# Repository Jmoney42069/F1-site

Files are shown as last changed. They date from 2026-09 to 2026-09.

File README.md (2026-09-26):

# dweilrobo

DIY autonomous floor-mopping robot: ESP32 for real-time control, home server for mapping and planning.

- `docs/01-engineering-study.md` — engineering study (architecture, sensors, power, layout, costs, open questions)
- `cad/layout.py` — parametric layout and weight/traction checks (`python3 cad/layout.py`, exits non-zero on failure)
- `cad/layout_top.svg` — generated top view

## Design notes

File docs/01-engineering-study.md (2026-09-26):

# dweilrobo — Engineering Study v0.1

Status: **pre-CAD study**. Nothing here is a purchase decision yet.
Companion files: `cad/layout.py` (parametric layout + load/traction checks), `cad/layout_top.svg` (its output).

Prices are **estimates** of typical 2026 AliExpress prices, not verified listings. The linked, verified BOM is the last step, done after the measurements in §11 are locked. That order is the CAD-first rule you set.

---

## 0. Summary

| Question | Answer |
|---|---|
| Is the €50–70 target realistic? | **Not with reliable mapping.** With a lidar, a robust MVP costs **€100–120** (recommended), or **€80–90** if you reuse cells and consumables. **€65–70** is possible only with no lidar and an old phone as a fixed overhead camera. See §13. |
| Minimum sensor set for real mapping + carpet avoidance | Wheel encoders + gyro (IMU) + **used Xiaomi LDS02RR lidar (~€16)** + 2 bumper switches + 2 downward ToF + the mop-motor encoders. Carpets are **no-go zones drawn on the map**. The onboard sensors are only a safety interlock. |
| Mop moisture sensing | **Don't make it the control loop.** Meter the water per pad by volume (mL/m²) with two peristaltic pumps. Commercial robots do the same. A direct sensor is a phase-3 experiment. See §4. |
| Battery | 3S1P 18650 (11.1 V, ~3 Ah, ~33 Wh), 3S BMS, 5 A fuse. Gives ~1.5 h against a ~17 W average draw. **Buy the cells from an EU shop, not AliExpress.** |
| Motors | 4× the same **JGA25-370 12 V ~130 rpm with Hall encoder**: 2 drive, 2 mop. One SKU gives you spares and stall detection everywhere. |
| Biggest mechanical risk | **The spring force on the mops takes load off the drive wheels.** The layout must keep enough weight on the wheels as the tank drains. `cad/layout.py` checks this, and the first layout **failed** it (§6.3). |

---

## 1. Where your spec is technically weak (read this first)

1. **"Measure each mop's moisture and regulate to 65%" is not practical with cheap parts.** The pad spins, gets dirty, and holds detergent. Its conductivity depends on water hardness and soap far more than on wetness. Resistive probes corrode (electrolysis). A capacitive sensor on a rotating, bouncing pad sees a varying air gap. No commercial mopping robot measures pad moisture. They all dose by area and time. → Control water **per square metre per pad**, and treat "moisture %" as an estimate the model calculates (§4).
2. **Odometry alone will not tell you "where have I cleaned".** A wet floor plus two rotating pads pulling sideways makes the wheels slip. You need an absolute reference. Lidar is the cheapest reliable one; a fixed overhead camera is the cheapest overall (§7).
3. **A camera on the robot is not the cheapest way to localize.** Visual SLAM from an ESP32-CAM over Wi-Fi has low fps, variable latency, motion blur and a camera 10 cm above a featureless floor. That is a research project. Use a camera for recognition later, not for pose.
4. **Your mops cannot lift, so the robot can never drive over a carpet.** Commercial robots lift their pads or detach them at the dock. We don't. So carpets are hard no-go zones, **inflated by the robot radius plus a margin**, because the pads sit behind the axle and swing when the robot turns.
5. **Automatic carpet detection with a €0.50 IR reflectance sensor (TCRT5000) is unreliable.** It measures colour and brightness, not material: a dark floor looks like a dark rug. The reliable signals are map zones, a height step at the rug edge, and extra drag on the pads.
6. **AliExpress 18650 cells** are the one AliExpress category to avoid ("9900 mAh" fakes, unknown chemistry). Saving €5 here risks a fire.
7. **4S is the wrong choice** here. The cheap, good H-bridge (TB6612FNG) is rated to 13.5 V, and 12 V motors are the common variant. 3S (9.0–12.6 V) matches both.
8. **The €50–70 target and "reliable map + coverage + carpet avoidance" pull against each other.** By your own rule (buy the €6 part if it makes the robot robust), the lidar earns its €16.
9. **Which ESP32 do you have?** The classic ESP32 (WROOM) and the S3 have hardware pulse counters (PCNT) for 4 encoders. **The ESP32-C3 has no PCNT and too few pins** — unsuitable as the main controller. The pin budget (§8.3) fits a classic DevKit with only 1 pin to spare.

---

## 2. Subsystem breakdown

```
MECHANICAL                 ELECTRICAL                     SOFTWARE
- base plate / frame       - 3S battery, BMS, fuse,       ESP32 firmware (real time)
- 2 drive pods               switch, charge jack            - wheel PID, odometry, IMU
  (motor+wheel)            - 5 V buck (ESP32, lidar)        - mop + pump control
- front caster             - 3x TB6612FNG                   - safety reflexes, watchdog
- 2 floating mop modules     (drive / mops / pumps)         - lidar driver, telemetry
- tank + cradle            - encoders, IMU, INA219        Server (ROS 2 in Docker)
- 2 pump brackets          - 2 ToF, 2 bumper switches       - bridge (UDP <-> topics)
- sealed battery box       - LDS02RR lidar                  - slam_toolbox (map/pose)
- electronics tray + lid   - wiring, connectors             - Nav2 + keep-out mask (carpet)
- front bumper                                              - coverage planner + cleaned layer
- lidar deck                                                - mop manager (dosing)
                                                            - dashboard (Foxglove / web)
```

---

## 3. Critical unknowns, ranked

| # | Unknown | Why it matters | How to settle it (cheap) |
|---|---|---|---|
| U1 | Pad friction coefficient and torque on **your** floor | Sizes the mop motors, drag, spring force | Bench test: a disc with a cloth, a known weight, a luggage scale on a lever arm |
| U2 | Wheel traction on a wet floor | Everything depends on the wheels not slipping | Pull test with the scale on a wet floor |
| U3 | Floor type (tile vs laminate/parquet) | Laminate/parquet tolerates very little water → dose limits | Tell me |
| U4 | Clearance under sofa / TV cabinet | Sets the maximum height (the lidar turret makes the robot ~150 mm tall) | Measure |
| U5 | Rug types and edge heights; do rugs move? | Moving rugs make map zones unreliable → onboard detection gets more important | Measure / tell me |
| U6 | Real dimensions of the chosen motor, pump, lidar and holder variants | The CAD depends on them; listings vary by ratio and seller | Measure after ordering **one** of each (§11) |
| U7 | Your ESP32 board | PCNT and pin count | Tell me the board name |
| U8 | 3D printer and bed size | Frame split into segments vs plywood | Tell me |

---

## 4. Moisture and water system

### 4.1 Sensing options, judged

| Method | Works? | Why |
|---|---|---|
| Resistive (2 electrodes in the pad) | Poor | Electrolysis corrodes the electrodes; reading depends on hardness and soap; contact on a rotating pad wears it |
| Capacitive (soil-sensor type) | Poor on a moving pad | Varying air gap, bounce, dirt. Works on a *stationary* reference sponge only |
| Conductivity with AC excitation | Relative trend only | Needs per-session calibration (dry vs soaked); still drifts with soap |
| Mop-motor load (encoder rpm at fixed PWM) | Weak for moisture | Floor, dirt and carpet dominate the signal. **Excellent for carpet/snag detection though** |
| **Metered water delivery (peristaltic)** | **Yes** | Volume per pump revolution is repeatable ±5–10%. Known mL/m² per pad is the quantity that matters |
| Tank level (capacitive, through the wall) | Yes | ESP32 touch pin + 2 copper-tape electrodes on the outside of the tank. Free. Detects empty tank and cross-checks the pumped volume |

### 4.2 Control approach (MVP)

```
target_dose  [mL/m²]   (per floor type, e.g. start at 3–5 mL/m², calibrate)
area_rate    [m²/s]  = speed × pad_width (from odometry, per pad)
pump_rate    [mL/s]  = target_dose × area_rate  (+ a pre-wet burst at start)
pump_pwm            ← calibration table mL/s → PWM (measured with a cup)
wetness_est  (per pad) integrates dosed water minus a transfer model, shown as your "LEFT 60% / RIGHT 43%"
```
Pumps stop immediately when the robot stops, a carpet or cliff is suspected, the tank is empty, the robot enters a no-go zone, or the server link is lost.

### 4.3 Pump choice: **two peristaltic pumps**, no splitter

- **One pump + Y-splitter:** the flow splits by tube resistance and air bubbles, so you can't control it per side. Cheap but gives an uneven result.
- **Diaphragm pump:** far too much flow (~1 L/min) for ~20 mL/min, and it **siphons/leaks when off**, so it needs a check valve and solenoid.
- **Peristaltic pump:** self-priming, **seals when stopped** (no leaks, no valves), flow ∝ speed, tolerates running dry. A second pump costs ~€5. **Worth it.** Pick the **low-flow variant (1×3 mm tube, ~5–40 mL/min at 12 V)**.

Flow needed: 5 mL/m² × 0.2 m/s × 0.27 m ≈ 0.27 mL/s ≈ **16 mL/min total**. A 25 m² room at 5 mL/m² uses ~125 mL, so a 300 mL tank is enough.

### 4.4 Leak-proof tank

- **No holes in the bottom of the tank.** The suction tube enters through the lid and reaches the bottom (weighted tip). Refilling = lift the lid and pull the tube out.
- The tank sits **over the axle** (so the balance doesn't change as it drains, §6.3). A drip tray under it drains *away* from the electronics.
- Pump → silicone tube → **stationary drip nozzle** over an annular trough in the rotating pad disc → holes → cloth. There is no rotating seal.

---

## 5. Motors, wheels, mops

### 5.1 Requirements

Mass ≈ **2.2 kg full** (see `cad/layout.py`).

- Drive: cruise 0.2 m/s, max ~0.4 m/s. Force ≈ rolling resistance (~0.6 N) + pad drag (~1.1 N while spinning, ~3.7 N if stalled) + a threshold/ramp margin → design for **~4 N total, ~2 N per wheel**. With a 65 mm wheel that is 0.065 N·m ≈ **0.7 kg·cm per motor** continuous, and more to climb a threshold.
- Speed: 0.4 m/s ÷ (π × 0.065 m) ≈ 118 rpm → **~130 rpm at 12 V**. It still gives ~100 rpm at 9.6 V; the PID handles the difference.
- Mops: friction torque ≈ ⅔·μ·N·R = ⅔ × 0.5 × 3.7 N × 0.065 m ≈ **0.8 kg·cm per pad**, 120–200 rpm.

### 5.2 Choice: JGA25-370, 12 V, ~130 rpm, with Hall encoder (×4)

- Gearbox Ø25 mm, 4 mm D-shaft (~10–12 mm long), 2× M3 on the gearbox face (spacing reported as 17 mm in some drawings — **VERIFY**), 11 PPR Hall encoder → ~1500–2000 counts per wheel revolution after ×4 decoding and the gear ratio. Rated torque at 130 rpm is roughly 1–2 kg·cm, stall much higher: enough margin for both jobs.
- Alternatives rejected:
  - **N20**: too weak for 2.2 kg plus pad drag.
  - **TT yellow motor**: plastic gears, backlash, poor encoders.
  - **BLDC**: needs an extra controller per motor and costs more, for no gain at these speeds.
- Mops use the **same SKU**: identical spares, and the encoder gives mop rpm, which is the carpet/snag/stall signal. Budget option: mops without an encoder (−€5 total), but then you lose that signal.
- Height: a vertical mop motor with encoder stands ~70 mm above the plate. If the height budget (U4) is tight, the lower alternative is the **JGY-370 worm-gear** motor mounted flat (right-angle output).

### 5.3 Wheels and caster

- 65 mm rubber wheels on a 4 mm D/hex coupler, or a printed hub with a TPU tyre. Axle height 32.5 mm → motor underside at ~20 mm → **ground clearance 20 mm**, enough for thresholds up to ~10 mm.
- One ball caster at the front (x = +150 mm). No rear caster: the mops are the rear support.

### 5.4 Mop module (floating)

```
      motor (fixed to plate, shaft down)
          │ 4 mm D-shaft → printed hex adapter
  ════════╪════════  base plate (z≈45–49)
          │  hex slider: hub slides ±8 mm on hex
       [spring]  preload screw → 2–5 N per pad
     ┌────┴────┐  TPU flex ring → a few degrees of tilt
     │ disc Ø130│  annular water trough + holes, hook tape underneath
     └─────────┘  microfiber pad (cut from cloth or bought circles), z 0–12
```
Pads: **Ø130 mm**, counter-rotating so the side forces cancel. The gyro heading loop corrects any leftover yaw. To swap a pad, pull it off the hook tape.

Known limitation: the pads sit ~42 mm inside the outline, so a strip ~4 cm wide along the walls stays unmopped. That is acceptable for v1.

---

## 6. Physical layout

### 6.1 Top view (from `cad/layout.py`)

Round Ø350 mm body, drive axle through the centre (so it can turn in place), mops at the rear, electronics at the front and top, water and battery away from the electronics.

top view

| Item | Position (x fwd, y left) mm |
|---|---|
| Drive wheels | x 0, y ±135 |
| Mop centres | x −85, y ±68, Ø130, 6 mm gap between them, 10 mm clearance to the wheels |
| Front caster | x +150 |
| Tank 80×100×50 (~330 mL usable) | over the axle, x −45…+35 |
| Battery 3S1P in a sealed box | between the mop motors, x −120…−60 |
| Electronics tray (ESP32, 3× TB6612, buck, INA219) | front, x +45…+135, raised, with a lid |
| Lidar | top deck, centred over the axle, highest point |
| Bumper | front 140° arc, 2 micro-switches |
| Cliff/rug-edge ToF ×2 | front-left/right, under the bumper, facing down |

### 6.2 Side stack (z)

| z (mm) | Layer |
|---|---|
| 0–12 | microfiber pad + disc |
| 12–30 | sliding hub, spring, ±8 mm travel |
| 20–45 | drive motors (axle at 32.5) |
| 45–49 | base plate (4 mm plywood or 3 mm PETG) |
| 49–100 | tank, pumps, battery box, electronics tray |
| 49–~120 | mop motors (vertical, with encoder) |
| ~125 | top deck |
| ~125–~165 | LDS02RR turret (**VERIFY height**) |

**Total height is about 160 mm.** This robot won't fit under most sofas. Decide this with measurement U4 before CAD.

### 6.3 Weight distribution — the check that failed first

Three groups carry the chassis: the wheels, the caster, and the mop springs. The spring force on the mops **pushes the chassis up** and puts load on the caster, both of which **take load off the wheels**. First layout (tank at the rear, battery in front, 4 N per pad):

```
[empty tank] traction 1.6 N vs stalled-pad drag 4.0 N   FAIL
```
Fix (current layout, all checks OK):
- The **tank goes over the axle**, so draining it doesn't move the centre of gravity (CG x ≈ −9 mm full and empty).
- The **battery goes behind the axle**.
- Spring preload is **3 N per pad** (adjustable 2–5 N), and the caster moves forward to x = +150.
- Result: wheel load 8.7–12.1 N → traction 3.5–4.8 N vs ~1.1 N drag with the pads spinning (≥3× margin).
- A **stalled pad (3.7 N drag) is at the traction limit**, so the firmware must stop the drive when mop rpm collapses. That also serves as the carpet/snag reflex.

Rule for the CAD: **any change to mass or position → rerun `python3 cad/layout.py`**. It exits non-zero on failure.

### 6.4 Water protection

Water sits rear/low, electronics front/high, with a printed splash wall between them. Keep the battery box sealed, route tubes with drip loops, put the electronics lid on top, and don't route water tubing over the electronics tray.

---

## 7. Navigation, mapping, localization

### 7.1 Comparison

| Option | Cost | Gives | Verdict |
|---|---|---|---|
| Wheel odometry | €0 (encoders) | Short-term motion | Needed, but drifts (slip on a wet floor) |
| IMU gyro (BMI160/MPU6050) | €2 | Heading, much better than odometry for turns | Needed |
| Front ToF array | €2 each | Near obstacles in a narrow cone | Nice-to-have; the bumper covers low obstacles |
| Ultrasonic | €1 | Wide, noisy, poor at angles | No |
| **2D lidar LDS02RR (used, ~€16)** | €16 | 360° scan → occupancy map, localization, obstacles | **Yes, the best value per euro.** Supported on ESP32 by the [kaiaai/LDS](https://github.com/kaiaai/LDS) library |
| New lidar (LD06/LD19/RPLIDAR A1) | €60–100 | Same, new | Only if the used LDS02RR disappoints |
| Fixed overhead camera + ArUco marker on the robot | €0 (old phone) to €20 | Absolute pose, top-down view, easy carpet drawing | **The €65 variant / backup.** Single room only, blocked under furniture, poor at night |
| ESP32-CAM on the robot | €7 | Recognition, future learning | Phase 4. Not for localization |
| Visual odometry / visual SLAM | — | — | Too fragile at this cost/latency |

### 7.2 Recommended MVP stack

- **ESP32:** reads the encoders (PCNT) and the gyro at 200 Hz, runs wheel-speed PID, and fuses them into an **odometry frame**. It also reads the LDS02RR and sends out scans.
- **Server:** ROS 2 in Docker.
  - `slam_toolbox` builds the map once, then localizes in it (map→odom correction).
  - Nav2 plans paths, with a **KeepoutFilter mask = carpets**.
  - A coverage node plans boustrophedon lanes (220 mm spacing = 266 mm pad width − 46 mm overlap) plus a clean-up pass over missed cells.
  - A **cleaned layer**: a 2 cm grid where cells under the two pad footprints are marked while the pads spin and are wet.
- **Command boundary** (your "no LLM on PWM" rule):
  - The server sends `(v, ω)` at 20 Hz with a 300 ms time-to-live, or motion primitives (`drive d at θ`, `rotate to θ`).
  - The ESP32 does all closed-loop control and owns every safety reflex.

### 7.3 Carpet strategy (your A vs B)

**B (map zones) is primary; A is a safety interlock.**
1. Draw the carpet polygons once on the map in the dashboard → keep-out mask, inflated by the robot radius plus 5 cm.
2. Interlocks (any one triggers pumps off → stop → back off):
   - The downward ToF sees the floor **rise ≥ ~5 mm** (rug edge) or **drop ≥ 25 mm** (cliff).
   - Mop rpm at fixed PWM drops (pad on pile or snagged).
   - Bumper hit.
3. Later: an ESP32-CAM with a small classifier on the server for rugs that move. Thin rugs (<5 mm) are only reliably handled by the map.

---

## 8. Electrical

### 8.1 Power budget (averages at cruise)

| Load | Avg | Peak |
|---|---|---|
| Drive 2× JGA25 | ~5.5 W | ~2 A each at stall (limited in firmware) |
| Mops 2× JGA25 | ~6.5 W | ~2 A each at stall |
| Pumps 2× (low duty) | ~1 W | 0.4 A each |
| LDS02RR (5 V) | ~2 W (**VERIFY**) | — |
| ESP32 Wi-Fi + sensors | ~1 W | 0.5 A bursts at 3.3 V |
| Buck losses | ~0.5 W | — |
| **Total** | **~17 W** | Realistic peak 3–4 A |

### 8.2 Battery and protection

- **3S1P 18650**, 3 × ~3000–3500 mAh (e.g. Samsung 35E / Molicel from an EU shop, or tested laptop cells). ~33 Wh, 80% usable → **~1.5 h**. A room takes ~15–25 min, so 1P is enough; add a second parallel string (2P) only if you add a second room.
- 3S **BMS with balancing**, ~10 A.
- **5 A fuse** right after the BMS, then a 10 A rocker switch (hard kill), then distribution.
- Charging: a dedicated **12.6 V CC/CV charger** into a DC jack wired to the BMS input. Never charge through the BMS alone. The dock later just parallels the DC jack.
- Rails: V_BAT goes to the 3× TB6612. A Mini560 buck (5 V, 3 A) feeds the ESP32's 5 V pin and the lidar. 3.3 V comes from the DevKit's LDO for the IMU, INA219, ToF and encoders (**power the encoders at 3.3 V**).
- Measurement: an INA219 on the main line gives battery voltage and current (the ESP32 ADC is too nonlinear).
- Wiring: 18 AWG main, 22–24 AWG motors, XT30 for the battery, JST-XH/PH for signals (JGA25 encoders come with a 6-pin PH2.0 lead).
- **Drivers:** TB6612FNG (4.5–13.5 V, 1.2 A continuous / 3.2 A peak per channel). No L298N (2 V loss, heat). DRV8833 is out (10.8 V max).

### 8.3 ESP32 pin budget (classic WROOM DevKit, ~24 usable GPIO)

| Function | Pins | Note |
|---|---|---|
| Drive encoders A/B ×2 | 4 | PCNT; input-only GPIO 34–39 OK |
| Mop encoders A only ×2 | 2 | Speed only; direction is fixed |
| Drive TB6612 | 4 | PWM on IN1/IN2, PWMx tied high |
| Mop TB6612 | 2 | Direction hard-wired, PWM only |
| Pump TB6612 | 2 | Same |
| Shared STBY (e-stop) | 1 | Low = all motors off |
| I2C (IMU, INA219, ToF ×2) | 2 | |
| ToF XSHUT | 1 | Re-address the second ToF at boot |
| Bumpers L/R | 1 | Resistor ladder on one ADC pin |
| Lidar RX + motor PWM | 2 | UART2 |
| Tank level | 1 | Touch pin |
| Status LED | 1 | |
| **Total** | **23 / ~24** | Tight → add a PCF8574 (€1) for margin, or use an ESP32-S3 |

---

## 9. Software architecture

### 9.1 ESP32 firmware (Arduino-ESP32 or ESP-IDF on FreeRTOS)

- `control` task, 100 Hz: encoders → wheel-speed PID → PWM; heading hold on the gyro; odometry integration; mop rpm loop; pump PWM from the dose rate.
- `sensors` task, 50–200 Hz: IMU (200 Hz with a bias estimate whenever the robot stands still), ToF (30 Hz), bumper (interrupt), INA219 (10 Hz), tank level (2 Hz).
- `lidar` task: LDS02RR decoding plus lidar motor speed control (kaiaai/LDS).
- `comm` task: UDP. Telemetry out at 50 Hz and scans at ~5 Hz (sequence number and timestamp in each). Commands in, each with a TTL.
- **Safety (always local, never waits on the server):**
  - Command expires (>300 ms) → stop the drive, pumps off, mops spin down.
  - Bumper or cliff → stop and reverse 3 cm.
  - Stall (PWM high, rpm ~0) → stop.
  - Rug-edge signal or mop-rpm drop → pumps off, stop.
  - Low battery (<9.6 V) → pumps off, return home.
  - Brown-out → everything off.

### 9.2 Server

- A Python **bridge** (UDP ↔ ROS 2 topics: `/odom`, `/imu`, `/scan`, `/cmd_vel`, `/mop/*`).
- `slam_toolbox`, Nav2 plus the keepout filter, the coverage node, and a `mop_manager` (dose model, wetness estimate, tank model).
- Logging goes to rosbag.
- Dashboard: Foxglove Studio at first (free, shows the map, pose and layers); later a small web UI for "draw carpet", "start cleaning" and "go home".
- Why ROS 2 and not all-custom: SLAM, costmaps, keep-out zones and planners already exist and are proven. You write the bridge, the coverage/cleaned layer and the mop manager. Why not micro-ROS on the ESP32: a small UDP protocol of your own is easier to debug and keeps the real-time side deterministic. The [kaiaai/firmware](https://github.com/kaiaai/firmware) project is a working reference for this same lidar + ESP32 + ROS 2 combination.

---

## 10. CAD architecture

- **Source of truth:** one parameter set.
  - Now: `cad/layout.py`.
  - Next: CadQuery (Python, git-friendly — fits your programming background) or FreeCAD/Onshape driven by a variables table with the same names.
- **Modules**, each separately printable, cuttable and replaceable:
  1. Base plate Ø350: 4 mm plywood (jigsaw/laser), or printed in 4 segments bolted together if your bed is ≤250 mm.
  2. Drive pod ×2 (mirrored): motor clamp + bracket, wheel.
  3. Mop module ×2: motor mount, hex adapter, sliding hub, spring + preload screw, disc Ø130 with trough, TPU flex ring, drip nozzle holder.
  4. Tank cradle (over the axle) + tank (a 350–500 mL food box, or printed PETG).
  5. Pump brackets ×2.
  6. Sealed battery box with the BMS, fuse and XT30 outside.
  7. Electronics tray: removable, raised, with a lid, drip edge and zip-tie points.
  8. Front bumper: 140° arc on slots, 2 micro-switches, spring return.
  9. ToF brackets ×2 (downward).
  10. Top deck + lidar mount on standoffs (the scan plane must clear everything).
- **Assembly rule:** M3 heat-set inserts in printed parts, no glue, and every module comes off with ≤4 screws.

---

## 11. Measurements to lock before the final BOM

Order **one sample** of each critical part first (motor, pump, lidar, wheel/coupler, BMS/holder, ~€40), measure, update `cad/layout.py`, and only then order the rest.

| # | Measure | Drives |
|---|---|---|
| M1 | Motor: gearbox length + motor + encoder length for the chosen ratio; face hole spacing and thread; shaft length/flat; encoder connector | Drive pod, mop mount, height |
| M2 | Wheel Ø, width, hub bore/coupler | Axle height, clearance, wheel_y |
| M3 | Pump: head Ø, motor length, flange holes, tube OD/ID | Bracket, tubing |
| M4 | LDS02RR: diameter, height, mounting holes, scan-plane height | Deck height, total height |
| M5 | 18650 holder/pack + BMS size | Battery box |
| M6 | Buck, TB6612 and INA219 board sizes + holes, ESP32 board size + holes | Electronics tray |
| M7 | Caster height (must match the wheel contact plane) | Caster mount |
| M8 | Your room: sofa/cabinet clearance, threshold heights, rug edge heights, door widths | Max height, wheel size, ToF thresholds |
| M9 | Pad test (U1) and traction test (U2) | Spring preload, motor margin |
| M10 | Printer bed size | Plate segmentation |

---

## 12. Candidate components (pre-verification)

| Part | Candidate | Key specs | Est. € |
|---|---|---|---|
| Drive motor ×2 | JGA25-370 12 V ~130 rpm, Hall encoder | Ø25, 4 mm D-shaft, 11 PPR | 12–16 |
| Mop motor ×2 | Same (or without encoder, or JGY-370 worm) | | 8–16 |
| Wheels ×2 | 65 mm rubber + 4 mm coupler | | 3–4 |
| Caster | Ball caster, height matched (M7) | | 1–2 |
| Motor drivers ×3 | TB6612FNG module | 4.5–13.5 V | 3–4 |
| Pumps ×2 | 12 V peristaltic, low-flow (1×3 mm tube, ~5–40 mL/min) | ~0.1–0.4 A | 8–12 |
| Tubing | Silicone 2×4 mm, 1 m + small nozzles | | 2 |
| Lidar | Xiaomi LDS02RR (used) | 5 V, UART 115200 | 15–18 |
| IMU | BMI160 (or MPU6050) | I2C | 2 |
| Power monitor | INA219 | I2C, 26 V | 1.5 |
| Downward ToF ×2 | VL53L0X | I2C | 3–4 |
| Bumper switches ×2 | KW12 lever micro-switch | | 1 |
| Buck | Mini560 5 V 3 A | 7–20 V in | 1.5 |
| BMS | 3S 10 A with balancing | | 1.5 |
| Cell holder | 3S 18650 (or spot-welded pack) | | 1.5 |
| Cells ×3 | Samsung 35E / Molicel — **EU shop** | | 11–13 |
| Charger | 12.6 V 1 A Li-ion CC/CV | | 4–6 |
| Protection | Fuse holder + 5 A fuses, 10 A rocker switch, XT30, DC jack | | 3–4 |
| Wiring | JST-XH kit, wire, heatshrink | | 3–5 |
| Mechanical | Spring assortment, M3 screws + inserts | | 3–5 |
| Pads | Microfiber cloth + hook tape | | 2–3 |
| Tank | 400–500 mL food box (local shop) | | 2 |
| Frame | 4 mm plywood or ~400 g PETG | | 5–8 |

---

## 13. Cost scenarios (estimates, to verify)

| Scenario | What changes | Est. total |
|---|---|---|
| **Recommended** | Everything in §12, new EU cells | **€105–120** |
| Lean | Reused laptop cells (tested), your own wire/screws/filament, mops without encoders | **€80–90** |
| Minimal | Lean, minus the lidar, plus an old phone as a fixed overhead camera tracking an ArUco marker; no ToF | **€65–70** (single room, blocked under furniture) |

Later upgrades: ESP32-CAM (~€7), a charging dock with pogo contacts (~€5 + print), 2P battery (+€12), a new lidar (LD06, ~€60+).

---

## 14. Build phases

0. **Bench:** one motor + encoder + PID on the ESP32; pump flow calibration; pad torque and traction tests (U1, U2).
1. **Base:** plate, drive pods, caster, battery system, teleop over Wi-Fi, watchdog, odometry and gyro.
2. **Map:** lidar, bridge, slam_toolbox map of the living room, Nav2 go-to-goal, keep-out carpets.
3. **Dry coverage:** coverage planner + cleaned layer with the mops spinning dry.
4. **Wet:** pumps, dose control, tank level, interlocks.
5. **Extras:** dock/return home, ESP32-CAM, automatic rug detection.

---

## 15. Questions for you (these block the CAD)

1. Which ESP32 board exactly (name/photo)?
2. Do you have a 3D printer? What bed size and filament?
3. Floor type: tile, laminate, parquet, or vinyl?
4. Room size, clearance under the furniture you want cleaned under, threshold and rug-edge heights, stairs yes/no.
5. Do rugs stay in fixed places?
6. Is ~€105–120 for the recommended version acceptable, or do we go Lean/Minimal?
7. Do you have an old Android phone (backup localization and a top-down view for drawing carpets)?

Sources: [JGA25-370 specs (abra-electronics)](https://abra-electronics.com/electromechanical/motors/gear-motors/metal-gearmotors/jga25-370-series/jga25-370-12v12-e-12vdc-12-rpm-dc-gear-motor-with-magnetic-encode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), [JGA25-370 datasheet](https://www.alldatasheet.com/datasheet-pdf/pdf/1567334/ETC2/JGA25-370.html), [LDS02RR on ESP32 (Maker's Pet)](https://makerspet.com/blog/how-to-connect-xiaomi-lds02rr-lidar-to-esp32/), [kaiaai/LDS](https://github.com/kaiaai/LDS), [kaiaai/awesome-2d-lidars](https://github.com/kaiaai/awesome-2d-lidars), [low-flow 12 V peristaltic pump example](https://www.pixelelectric.com/mini-dc-pumps-valves-accessories/intllab-12v-dosing-peristaltic-liquid-pump-5-40ml-min/).

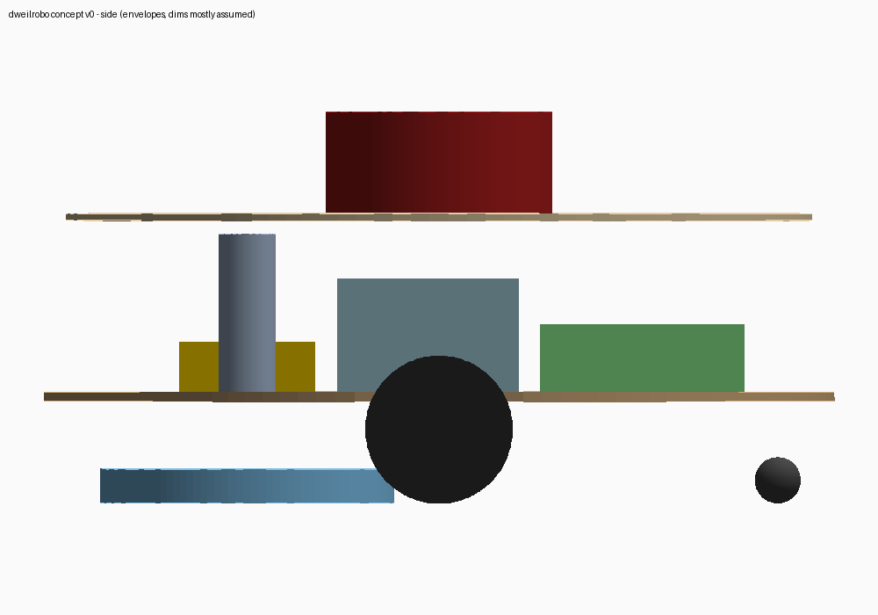
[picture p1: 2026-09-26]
cad/out/concept_v0_side.png

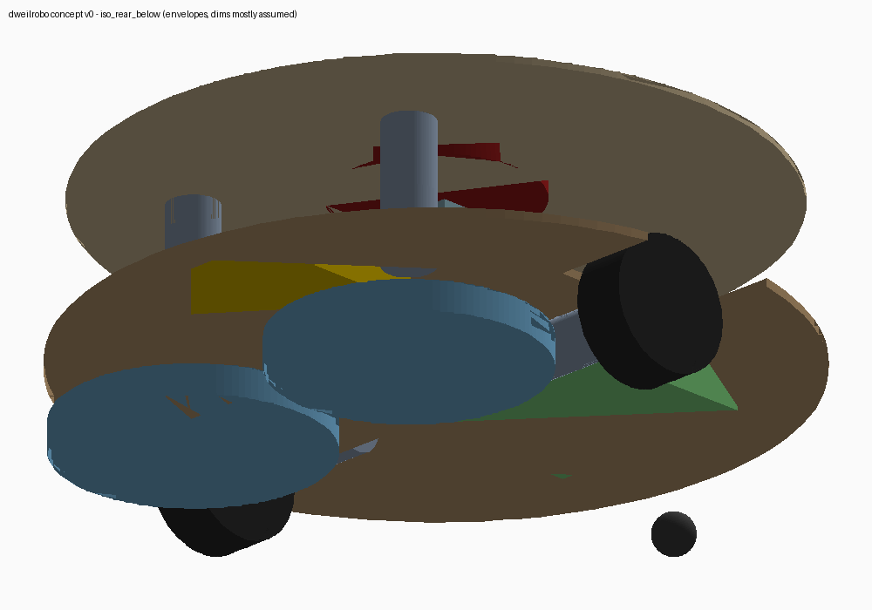
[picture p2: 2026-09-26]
cad/out/concept_v0_iso_rear_below.png

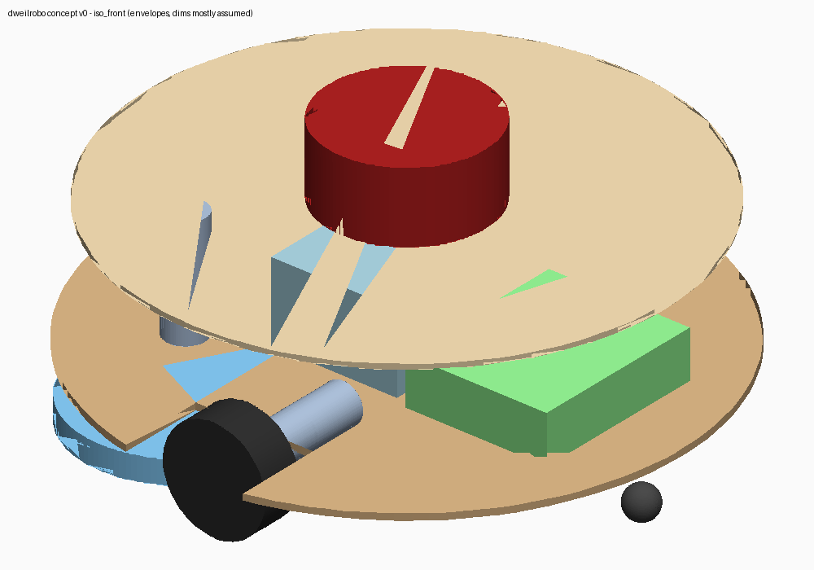
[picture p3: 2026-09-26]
cad/out/concept_v0_iso_front.png

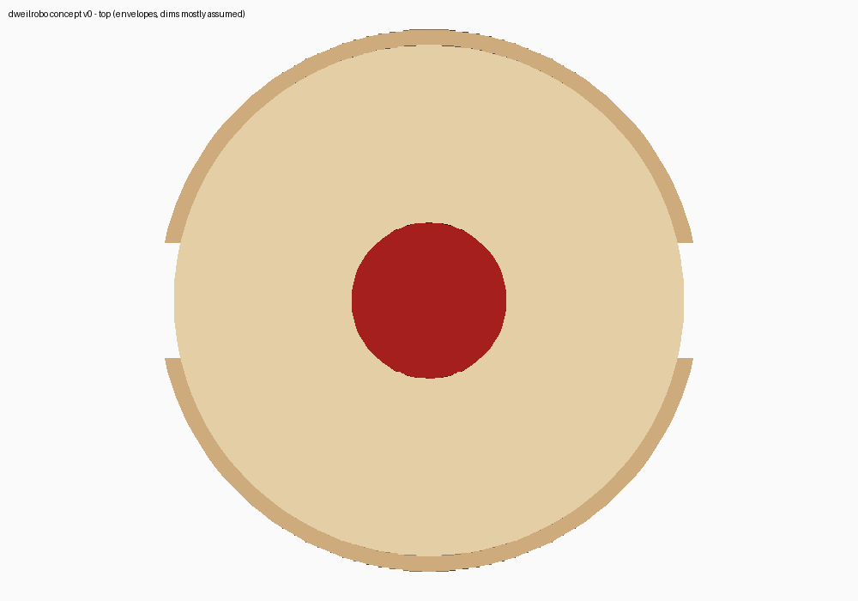
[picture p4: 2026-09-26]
cad/out/concept_v0_top.png

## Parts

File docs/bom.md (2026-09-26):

# Bestellijst (BOM) — werkversie

Status: ✅ besteld · 🛒 in mandje zetten · 🏪 lokaal kopen · 🇳🇱 EU-winkel

| # | Onderdeel | Zoekterm (AliExpress) | Kies / let op | Aantal | Status |
|---|---|---|---|---|---|
| 1 | Aandrijfmotor | JGA25-370 Hall encoder | 12V, 130 RPM, met encoder + bracket | 2 | ✅ |
| 2 | ESP32-S3 | ESP32-S3 DevKitC-1 N16R8 | N16R8, 2× USB-C | 1 | ✅ |
| 3 | Motordriver | TB6612FNG module | TB6612, niet DRV8833 | 4 | ✅ |
| 4 | Wiel | 65mm wheel 4mm coupling | gat moet op 4 mm D-as passen (geen TT-motorwiel) | 2 | 🛒 |
| 5 | Zwenkwiel | ball caster metal | metaal, kogel ±15–25 mm | 1 | 🛒 |
| 6 | Mopmotor | JGA25-370 12V 130RPM (Choice) | Package A (alleen motor), zonder encoder is OK | 2 | 🛒 |
| 7 | Waterpomp | 12V peristaltic pump | 12V, laagste debiet (1×3 mm slang) | 2 | 🛒 |
| 8 | Slang | silicone tube 2x4mm | maat moet op de pomp passen, 1–2 m | 1 | 🛒 |
| 9 | 5V-omvormer | Mini560 5V buck | 5V-uitgang | 2 | 🛒 |
| 10 | Stroommeter | INA219 module | | 1 | 🛒 |
| 11 | Gyro | BMI160 module | of MPU6050 | 1 | 🛒 |
| 12 | Afstandssensor | VL53L0X module | | 2 | 🛒 |
| 13 | Bumperschakelaar | micro switch lever KW12 | met hendeltje | set | 🛒 |
| 14 | Lidar | LDS02RR lidar | gebruikt, met kabel | 1 | 🛒 |
| 15 | Batterijhouder | 18650 3S holder with wires | 3 cellen in serie | 1 | 🛒 |
| 16 | BMS | 3S 10A BMS balance | met balansering | 1 | 🛒 |
| 17 | Lader | 12.6V 1A charger | EU-stekker, 5.5×2.1 plug | 1 | 🛒 |
| 18 | Zekering | inline blade fuse holder | + 5A mesjeszekeringen | 1 | 🛒 |
| 19 | Schakelaar | rocker switch 10A | | 2 | 🛒 |
| 20 | Stekkers | XT30 connector | man+vrouw paar | 2 paar | 🛒 |
| 21 | DC-jack | DC jack female 5.5x2.1 screw terminal | voor adapter/lader | 2 | 🛒 |
| 22 | Kabels | JST XH 2.54 pre-crimped cable | 2/4/6-pins | set | 🛒 |
| 23 | Draad | silicone wire 18AWG + 22AWG | | elk 1 | 🛒 |
| 24 | Schroeven | M3 screw assortment + M3 heat set insert | | set | 🛒 |
| 25 | Condensator | electrolytic capacitor 100uF 25V | | set | 🛒 |
| 26 | Veren | compression spring assortment | kleine drukveren | set | 🛒 |
| 27 | Breadboard | breadboard + jumper wires | M-M en M-F | 1 | 🛒/🏪 |
| 28 | Accucellen | — | Samsung 35E of Molicel, via nkon.nl | 3 | 🇳🇱 |
| 29 | Multimeter, schuifmaat, 12V 2A-adapter, krimpkous | — | | 1 | 🏪 |
| 30 | Microvezeldoek, klittenband, bakje (tank) | — | | 1 | 🏪 |

Let op: €3 invoerheffing per soort product (EU, sinds 1 juli 2026).

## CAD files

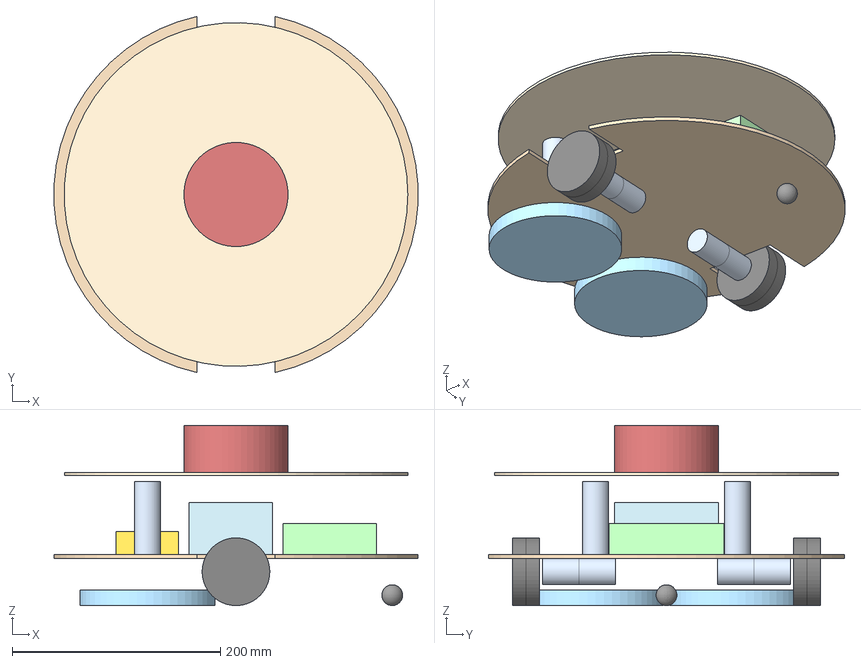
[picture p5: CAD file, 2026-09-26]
cad/out/concept_v0.step
349.5 x 341.9 x 173.0 mm
base_plate
wheel_L
drive_motor_L
wheel_R
drive_motor_R
caster
pad_L
mop_motor_L
pad_R
mop_motor_R
tank
battery
electronics
top_deck
lidar

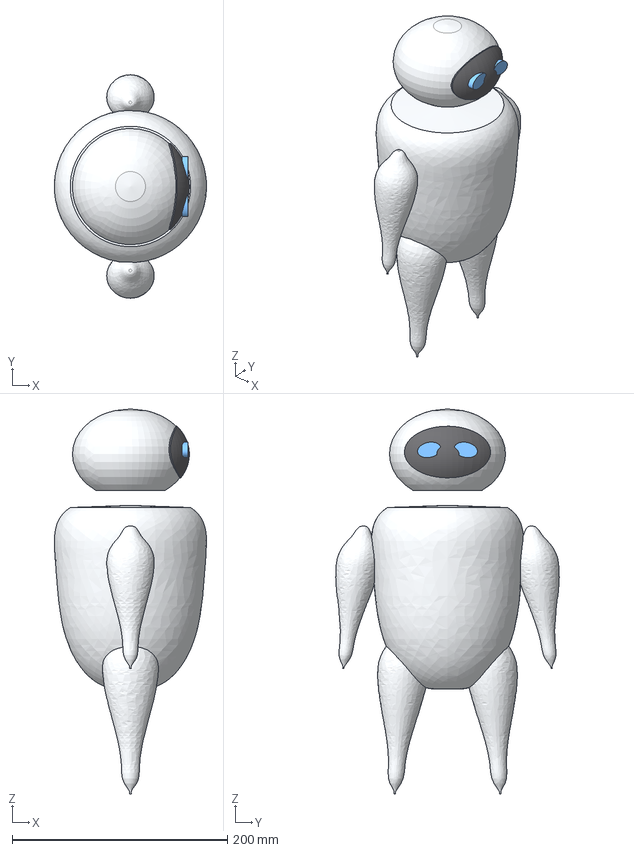
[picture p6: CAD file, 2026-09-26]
eve/out/eve_v0.step
141.5 x 207.8 x 358.0 mm
head
visor
eye_L
arm_L
leg_L
eye_R
arm_R
leg_R

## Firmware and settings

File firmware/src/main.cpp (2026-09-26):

// dweilrobo firmware v0.1: connect to the home hub, answer pings, run commands.
// Safety rule for all later versions: no hub message for LINK_TIMEOUT_MS -> safe state.
#include <Arduino.h>
#include <WiFi.h>
#include <WebSocketsClient.h>
#include <ArduinoJson.h>
#include "config.h"

static const char *FW_VERSION = "0.1.0";
static const uint32_t LINK_TIMEOUT_MS = 1000;
static const uint32_t TELEMETRY_MS = 1000;

WebSocketsClient ws;
uint32_t lastHubMsg = 0;
uint32_t lastTelemetry = 0;
bool linkUp = false;

void setLed(uint8_t r, uint8_t g, uint8_t b) { neopixelWrite(RGB_PIN, r, g, b); }

void safeState() {
  // v0.1 only has the LED; motors and pumps get switched off here later.
  setLed(8, 4, 0);  // dim orange = no link
}

void sendJson(JsonDocument &doc) {
  String out;
  serializeJson(doc, out);
  ws.sendTXT(out);
}

void sendHello() {
  JsonDocument doc;
  doc["type"] = "hello";
  doc["id"] = DEVICE_ID;
  doc["fw"] = FW_VERSION;
  JsonArray caps = doc["caps"].to<JsonArray>();
  caps.add("led");
  sendJson(doc);
}

void sendAck(uint32_t cmdId, bool ok, const char *error) {
  JsonDocument doc;
  doc["type"] = "ack";
  doc["cmd_id"] = cmdId;
  doc["ok"] = ok;
  if (error) doc["error"] = error; else doc["error"] = nullptr;
  sendJson(doc);
}

void handleMessage(const uint8_t *payload, size_t len) {
  JsonDocument msg;
  if (deserializeJson(msg, payload, len)) return;
  lastHubMsg = millis();
  const char *type = msg["type"] | "";

  if (strcmp(type, "ping") == 0) {
    JsonDocument pong;
    pong["type"] = "pong";
    pong["t"] = msg["t"];
    sendJson(pong);
  } else if (strcmp(type, "cmd") == 0) {
    uint32_t id = msg["cmd_id"] | 0;
    const char *name = msg["name"] | "";
    if (strcmp(name, "led") == 0) {
      setLed(msg["args"]["r"] | 0, msg["args"]["g"] | 0, msg["args"]["b"] | 0);
      sendAck(id, true, nullptr);
    } else {
      sendAck(id, false, "unknown command");
    }
  }
}

void onWsEvent(WStype_t type, uint8_t *payload, size_t length) {
  switch (type) {
    case WStype_CONNECTED:
      Serial.println("hub connected");
      sendHello();
      lastHubMsg = millis();
      linkUp = true;
      setLed(0, 8, 0);
      break;
    case WStype_DISCONNECTED:
      if (linkUp) Serial.println("hub disconnected");
      linkUp = false;
      safeState();
      break;
    case WStype_TEXT:
      handleMessage(payload, length);
      break;
    default:
      break;
  }
}

void setup() {
  Serial.begin(115200);
  safeState();
  WiFi.mode(WIFI_STA);
  WiFi.setSleep(false);  // Wi-Fi power save adds 100+ ms latency spikes
  WiFi.begin(WIFI_SSID, WIFI_PASS);
  Serial.print("wifi");
  while (WiFi.status() != WL_CONNECTED) { delay(250); Serial.print("."); }
  Serial.printf("\nip %s rssi %d\n", WiFi.localIP().toString().c_str(), WiFi.RSSI());

  String path = String("/ws/device?token=") + DEVICE_TOKEN;
  ws.begin(HUB_HOST, HUB_PORT, path.c_str());
  ws.onEvent(onWsEvent);
  ws.setReconnectInterval(1000);
}

void loop() {
  ws.loop();
  uint32_t now = millis();
  if (linkUp && now - lastHubMsg > LINK_TIMEOUT_MS) {
    Serial.println("link timeout -> safe state");
    linkUp = false;
    safeState();
    ws.disconnect();
  }
  if (linkUp && now - lastTelemetry > TELEMETRY_MS) {
    lastTelemetry = now;
    JsonDocument t;
    t["type"] = "telemetry";
    t["uptime_ms"] = now;
    t["rssi"] = WiFi.RSSI();
    t["free_heap"] = ESP.getFreeHeap();
    sendJson(t);
  }
}

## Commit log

2026-04-20 feat: F1 scroll-sequence assembly site
    Full Next.js site with video-scrubbing scroll animation:
    - 600vh pinned section maps scroll progress to video.currentTime
    - Nav locked behind assembly completion (opacity/transform transition)
    - Post-assembly content: stats, tech, drivers sections
    - Light grey studio theme matching Kling AI video aesthetic
    - Red accent (#e30613), carbon black, white type system
    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
2026-04-20 fix: rename video to assembly.mp4
2026-04-20 feat: canvas frame sequence (121 frames) replacing video scrubbing
2026-04-20 fix: 1920px HQ frames, matched bg gradient, 1.45x zoom on car
2026-04-20 fix: per-frame background color sampling matches video gradient exactly
2026-09-26 cad: parametric CadQuery concept assembly v0 (round pads) with collision checks and renders
    Claude-Session: https://claude.ai/code/session_01WYGChBQsKJsiJefKn1FPYe
    [concept_v0.step]
2026-09-26 cad: interactive 3D viewer (GLB + three.js) for the concept model
    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
2026-09-26 docs: working bill of materials
    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
2026-09-26 eve: shape study v0 of an EVE-style balancing robot, shared 3D viewer generator
    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
    [eve_v0.step]
2026-09-26 eve: rounder shape v1, no wheels, rounded limb tips
    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
    [eve_v0.step]
2026-09-26 server: first home hub (WebSocket device hub, command API, test page, fake device)
    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
2026-09-26 chore: remove accidentally committed pip wheels
    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
